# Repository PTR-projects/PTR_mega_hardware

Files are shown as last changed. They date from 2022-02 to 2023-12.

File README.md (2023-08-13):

# KPPTR-hardware

Welcome to the KPPTR-hardware repository! This repository contains the design files for the hardware components used in the KPPTR project. The design files have been created using KiCad 6.0, a powerful open-source electronics design automation suite.

## Project Overview

The design files in this repository correspond to the hardware components that make up the KPPTR project, which enhances the capabilities of DIY amateur rockets and high-altitude balloons. The design files have been crafted using KiCad 6.0, a popular and user-friendly tool for creating electronic schematics and PCB layouts. Both hardware and sofware were developed by PTR member!

## Design Files

The repository includes design files for the various hardware components used in the KPPTR project, including:

- **Schematics**: Detailed electronic schematics that illustrate the connections and components used in the design.
- **PCB Layouts**: PCB layout designs that define the placement and routing of components on the printed circuit board.
- **Libraries**: Custom component libraries and footprints used in the project.

## Getting Started

To access and work with the design files, follow these steps:

1. Clone the repository to your local machine.
2. Install [KiCad 6.0](https://www.kicad.org/download/) if you haven't already.
3. Open the KiCad project files (`.pro` files) in the appropriate subdirectories to access the schematics and PCB layouts.

Feel free to explore the design files and customize them to suit your specific needs. If you make any improvements or modifications to the hardware designs, consider contributing back to the repository to help the community.

## Contributors

- [bartekM](https://gitlab.com/space.tech)
- [https://gitlab.com/andrewziebinski](https://gitlab.com/andrewziebinski)
- [https://gitlab.com/Bdabrowsky](https://gitlab.com/Bdabrowsky)
- [https://gitlab.com/krecik1](https://gitlab.com/krecik1)
- [https://gitlab.com/US_air_force](https://gitlab.com/US_air_force)
- [https://gitlab.com/karmelek96](https://gitlab.com/karmelek96)
- and many others!

## License

This project is licensed under the [MIT License](LICENSE). You can freely use, modify, and distribute the code in accordance with the terms of the license.

Unless required by applicable law or agreed to in writing, this
software is distributed on an "AS IS" BASIS, WITHOUT WARRANTIES OR
CONDITIONS OF ANY KIND, either express or implied.

Thank you for your interest in KPPTR-firmware! If you have any questions or feedback, please don't hesitate to reach out to us. Happy coding and safe flights!

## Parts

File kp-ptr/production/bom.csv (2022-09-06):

Designator | Footprint | Quantity | Value | LCSC Part #
D2 | D_0402_1005Metric | 1 | TBD
R27 | R_0402_1005Metric | 1 | 10k
R34 | R_0402_1005Metric | 1 | 1k
R16 | R_0402_1005Metric | 1 | 10k
R42 | R_0402_1005Metric | 1 | 10k
R59 | R_0402_1005Metric | 1 | 100k
R39 | R_0402_1005Metric | 1 | 1k
R37 | R_0402_1005Metric | 1 | 1k
R15 | R_0402_1005Metric | 1 | 10k
C3 | C_0603_1608Metric | 1 | 10u
R60 | R_0402_1005Metric | 1 | 10k
F1 | Fuse_1210_3225Metric | 1 | 500mA
C24 | C_0603_1608Metric | 1 | 4.7uF
R41 | R_0402_1005Metric | 1 | 1k
R38 | R_0402_1005Metric | 1 | 1k
R8 | R_0402_1005Metric | 1 | 0R
C6 | C_0402_1005Metric | 1 | 100n
C46 | C_0402_1005Metric | 1 | 100nF
U12 | SOT95P275X110-6N | 1 | NL27WZU04DBVT1G
R14 | R_0402_1005Metric | 1 | 4k7
R24 | R_0402_1005Metric | 1 | 10k
C37 | C_0402_1005Metric | 1 | 1uF
R44 | R_0402_1005Metric | 1 | 10k
R36 | R_0402_1005Metric | 1 | 1k
R54 | R_0402_1005Metric | 1 | 10k
Y1 | XTAL_TSX-3225_16.0000MF18X-AC3 | 1 | 7M40000005-40MHz
R25 | R_0402_1005Metric | 1 | 10k
L3 | L_0402_1005Metric | 1 | 10nH
U9 | LDFM33PVR | 1 | LDFM33PVR
C32 | C_0402_1005Metric | 1 | TBD
R50 | R_0402_1005Metric | 1 | 10k
C17 | C_0402_1005Metric | 1 | 1uF
U4 | LIS331 | 1 | H3LIS331
C23 | C_0603_1608Metric | 1 | 4.7uF
C16 | C_0603_1608Metric | 1 | 10uF
R4 | R_0402_1005Metric | 1 | 1k
F3 | Fuse_1210_3225Metric | 1 | 500mA
R55 | R_0402_1005Metric | 1 | 10k
C14 | C_0402_1005Metric | 1 | 12p
C10 | C_0402_1005Metric | 1 | 100n
C49 | C_0402_1005Metric | 1 | 1uF
U6 | SON50P260X260X55-11N | 1 | NJG1156PCD
C42 | C_0402_1005Metric | 1 | 100n
R1 | R_0402_1005Metric | 1 | 1k
C4 | C_0402_1005Metric | 1 | 1u
R52 | R_0402_1005Metric | 1 | 10k
U11 | SON127P500X600X80-9N | 1 | W25Q128JVS
R35 | R_0402_1005Metric | 1 | 1k
L1 | L_0402_1005Metric | 1 | 1.8nH
R58 | R_0402_1005Metric | 1 | 100k
C41 | C_0402_1005Metric | 1 | 100n
F2 | Fuse_1210_3225Metric | 1 | 500mA
AE1 | AMCA31-2R450G-S1F-T3 | 1 | Antenna_Chip
R32 | R_0402_1005Metric | 1 | 10k
D3 | D_SOD-123 | 1 | D_Schottky
C28 | C_0603_1608Metric | 1 | 10uF
C11 | C_0402_1005Metric | 1 | 100n
C12 | C_0402_1005Metric | 1 | 0.1uF
Q4 | DMC2025UFDB | 1 | DMC2025UFDB_v2
R51 | R_0402_1005Metric | 1 | 10k
U1 | ESP32-S3 | 1 | ESP32-S3FN8
R3 | R_0402_1005Metric | 1 | 1k
R30 | R_0402_1005Metric | 1 | DNP
C22 | C_0402_1005Metric | 1 | 100nF
R17 | R_0402_1005Metric | 1 | 100R
FB2 | R_0603_1608Metric | 1 | 1000mA
R21 | R_1206_3216Metric | 1 | DNP
C26 | C_0402_1005Metric | 1 | 1nF
R12 | R_0402_1005Metric | 1 | 1k
F5 | Fuse_1210_3225Metric | 1 | 500mA
C39 | C_0402_1005Metric | 1 | 100nF
U3 | MMC5983MA | 1 | MMC5983MA
R6 | R_0402_1005Metric | 1 | 22R
R47 | R_0402_1005Metric | 1 | 10k
R49 | R_0402_1005Metric | 1 | 100k
R29 | R_0402_1005Metric | 1 | 10k
U2 | MS5607 | 1 | MS560702BA03-50
D4 | D_SOD-123 | 1 | D_Schottky
C9 | C_0402_1005Metric | 1 | 1u
R19 | R_0402_1005Metric | 1 | 100k
C33 | C_0402_1005Metric | 1 | 10n
C50 | C_0402_1005Metric | 1 | 1uF
R13 | R_0402_1005Metric | 1 | 220
R20 | R_0402_1005Metric | 1 | 10k
U5 | XCVR_L76-L | 1 | L76-L
Q5 | DMC2025UFDB | 1 | DMC2025UFDB_v2
R2 | R_0402_1005Metric | 1 | 1k
R11 | R_0402_1005Metric | 1 | 10k
L2 | L_0402_1005Metric | 1 | 2nH
C21 | C_0402_1005Metric | 1 | 100nF
C1 | C_0402_1005Metric | 1 | 4pF
C5 | C_0402_1005Metric | 1 | 1u
R18 | R_0402_1005Metric | 1 | 10k
C20 | C_0603_1608Metric | 1 | 10uF
R23 | R_0402_1005Metric | 1 | 20k
R43 | R_0402_1005Metric | 1 | 10k
R7 | R_0402_1005Metric | 1 | 22R
R9 | R_0402_1005Metric | 1 | 10k
C13 | C_0402_1005Metric | 1 | 1uF
R56 | R_0402_1005Metric | 1 | 10k
C19 | C_0402_1005Metric | 1 | 100nF
C36 | C_0603_1608Metric | 1 | 10u
C44 | C_0402_1005Metric | 1 | 100nF
R45 | R_0402_1005Metric | 1 | 10k
R5 | R_0402_1005Metric | 1 | 10k
R28 | R_0402_1005Metric | 1 | 2k2
FB1 | R_0402_1005Metric | 1 | 200mA
C30 | C_0402_1005Metric | 1 | DNP
F4 | Fuse_1210_3225Metric | 1 | 500mA
C38 | C_0402_1005Metric | 1 | 1uF
D11 | D_SOD-123 | 1 | 1N4148
R48 | R_0402_1005Metric | 1 | 100k
U8 | AZ1117CH-5.0TRG1 | 1 | AZ1117CH-5.0TRG1
R57 | R_0402_1005Metric | 1 | 10k
C31 | C_0402_1005Metric | 1 | 100nF
C40 | C_0402_1005Metric | 1 | 1uF
C43 | C_0603_1608Metric | 1 | 4u7
C7 | C_0402_1005Metric | 1 | 100n
C47 | C_0402_1005Metric | 1 | 1uF
C45 | C_0402_1005Metric | 1 | 100nF
U10 | SOT-23-6 | 1 | USBLC6-2SC6
Q2 | DMC2025UFDB | 1 | DMC2025UFDB_v2
R61 | R_0402_1005Metric | 1 | 10k
Q1 | SOT-23 | 1 | NMOS_SOT23
R62 | R_0402_1005Metric | 1 | 10k
C25 | C_0402_1005Metric | 1 | 56pF
R63 | R_0402_1005Metric | 1 | 10k
C29 | C_0402_1005Metric | 1 | 100nF
Q3 | DMC2025UFDB | 1 | DMC2025UFDB_v2
U7 | LSM6DSO32 | 1 | LSM6DSO32
R31 | R_0402_1005Metric | 1 | 10k
C15 | C_0402_1005Metric | 1 | 12p
C18 | C_0402_1005Metric | 1 | 100nF
R10 | R_0402_1005Metric | 1 | 10k
C2 | C_0402_1005Metric | 1 | 5pF
R40 | R_0402_1005Metric | 1 | 1k
C48 | C_0402_1005Metric | 1 | 1uF
C8 | C_0402_1005Metric | 1 | 10n
R53 | R_0402_1005Metric | 1 | 10k
C35 | C_0603_1608Metric | 1 | 10u
R22 | R_0402_1005Metric | 1 | 100k
R26 | R_0402_1005Metric | 1 | 100k
R46 | R_0402_1005Metric | 1 | 10k
J1 | PinHeader_1x06_P1.27mm_Vertical | 1 | ESP32_PROG_CON
C34 | CP_Elec_10x10 | 1 | TBD
J2 | TerminalBlock_TE_282834-2_1x02_P2.54mm_Horizontal | 1 | Conn_01x02
IC1 | E22-900M22S | 1 | E22-900M22S
J7 | JST_GH_BM10B-GHS-TBT_1x10-1MP_P1.25mm_Vertical | 1 | Conn_01x10_Male
J4 | USB_C_213716 | 1 | USB_C_Receptacle_USB2.0
J10 | TerminalBlock_TE_282834-2_1x02_P2.54mm_Horizontal | 1 | Conn_01x02
D15 | WS2812B-2020 | 1 | WS2812B-2020
J5 | SMA_Amphenol_132289_EdgeMount | 1 | u.fl
ANT2 | APAE1575 13x13x4mm GPS Patch Antenna | 1 | APAE1575R1340ABDD6-T
D12 | LED_0603_1608Metric | 1 | LED
J8 | JST_GH_BM06B-GHS-TBT_1x06-1MP_P1.25mm_Vertical | 1 | Conn_01x06_Male
J12 | TerminalBlock_TE_282834-2_1x02_P2.54mm_Horizontal | 1 | Conn_01x02
D7 | LED_0603_1608Metric | 1 | G
D8 | LED_0603_1608Metric | 1 | LED
D1 | LED_0603_1608Metric | 1 | BLUE
LS1 | Buzzer_12x9.5RM7.6 | 1 | CBT-09427-SMT
J6 | JST_GH_BM06B-GHS-TBT_1x06-1MP_P1.25mm_Vertical | 1 | Conn_01x06_Male
J13 | TerminalBlock_TE_282834-2_1x02_P2.54mm_Horizontal | 1 | Conn_01x02
J3 | TerminalBlock_TE_282834-2_1x02_P2.54mm_Horizontal | 1 | Conn_01x02
D9 | D_0402_1005Metric | 1 | TBD
D13 | WS2812B-2020 | 1 | WS2812B-2020
J11 | TerminalBlock_TE_282834-2_1x02_P2.54mm_Horizontal | 1 | Conn_01x02
J9 | TerminalBlock_TE_282834-2_1x02_P2.54mm_Horizontal | 1 | Conn_01x02_Male
D14 | WS2812B-2020 | 1 | WS2812B-2020
D5 | LED_0603_1608Metric | 1 | G
D10 | LED_0603_1608Metric | 1 | LED
D6 | LED_0603_1608Metric | 1 | G

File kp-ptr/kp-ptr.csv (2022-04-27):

Source: | E:\KPPTRv3\kp-ptr\kp-ptr.kicad_sch
Date: | 26.04.2022 18:11:41
Tool: | Eeschema (6.0.0)
Generator: | C:\Program Files\KiCad\6.0\bin\scripting\plugins/bom_csv_grouped_by_value.py
Component Count: | 149
Individual Components:
Item | Qty | Reference(s) | Value | LibPart | Footprint | Datasheet | AVAILABILITY | Comment | DESCRIPTION | EU_RoHS_Compliance | Field4 | MANUFACTURER | MAXIMUM_PACKAGE_HEIGHT | MF | MP | PACKAGE | PARTREV | PRICE | STANDARD
 |  | ANT1 | TBD | Device:R | Resistor_SMD:R_0402_1005Metric_Pad0.72x0.64mm_HandSolder | ~
 |  | C1 | TBD | Device:C | Capacitor_SMD:C_01005_0402Metric_Pad0.57x0.30mm_HandSolder | ~
 |  | C2 | TBD | Device:C | Capacitor_SMD:C_01005_0402Metric_Pad0.57x0.30mm_HandSolder | ~
 |  | C3 | TBD | Device:C | Capacitor_SMD:C_01005_0402Metric_Pad0.57x0.30mm_HandSolder | ~
 |  | C4 | 10u | Device:C | Capacitor_SMD:C_01005_0402Metric_Pad0.57x0.30mm_HandSolder | ~
 |  | C5 | 1u | Device:C | Capacitor_SMD:C_01005_0402Metric_Pad0.57x0.30mm_HandSolder | ~
 |  | C6 | 1u | Device:C | Capacitor_SMD:C_01005_0402Metric_Pad0.57x0.30mm_HandSolder | ~
 |  | C7 | 100n | Device:C | Capacitor_SMD:C_01005_0402Metric_Pad0.57x0.30mm_HandSolder | ~
 |  | C8 | TBD | Device:C | Capacitor_SMD:C_01005_0402Metric_Pad0.57x0.30mm_HandSolder | ~
 |  | C9 | 10u | Device:C | Capacitor_SMD:C_01005_0402Metric_Pad0.57x0.30mm_HandSolder | ~
 |  | C10 | 1u | Device:C | Capacitor_SMD:C_01005_0402Metric_Pad0.57x0.30mm_HandSolder | ~
 |  | C11 | 100n | Device:C | Capacitor_SMD:C_01005_0402Metric_Pad0.57x0.30mm_HandSolder | ~
 |  | C12 | 100n | Device:C | Capacitor_SMD:C_01005_0402Metric_Pad0.57x0.30mm_HandSolder | ~
 |  | C13 | 0.1uF | Device:C | Capacitor_SMD:C_01005_0402Metric_Pad0.57x0.30mm_HandSolder | ~
 |  | C14 | 1uF | Device:C | Capacitor_SMD:C_01005_0402Metric_Pad0.57x0.30mm_HandSolder | ~
 |  | C15 | 12p | Device:C | Capacitor_SMD:C_01005_0402Metric_Pad0.57x0.30mm_HandSolder | ~
 |  | C16 | 12p | Device:C | Capacitor_SMD:C_01005_0402Metric_Pad0.57x0.30mm_HandSolder | ~
 |  | C17 | 100nF | Device:C | Capacitor_SMD:C_01005_0402Metric_Pad0.57x0.30mm_HandSolder | ~
 |  | C18 | 47p | Device:C | Capacitor_SMD:C_01005_0402Metric_Pad0.57x0.30mm_HandSolder | ~
 |  | C19 | DNP | Device:C | Capacitor_SMD:C_01005_0402Metric_Pad0.57x0.30mm_HandSolder | ~
 |  | C20 | 10uF | Device:C | Capacitor_SMD:C_01005_0402Metric_Pad0.57x0.30mm_HandSolder | ~
 |  | C21 | 1uF | Device:C | Capacitor_SMD:C_01005_0402Metric_Pad0.57x0.30mm_HandSolder | ~
 |  | C22 | 100nF | Device:C | Capacitor_SMD:C_01005_0402Metric_Pad0.57x0.30mm_HandSolder | ~
 |  | C23 | 10uF | Device:C | Capacitor_SMD:C_01005_0402Metric_Pad0.57x0.30mm_HandSolder | ~
 |  | C24 | 100nF | Device:C | Capacitor_SMD:C_01005_0402Metric_Pad0.57x0.30mm_HandSolder | ~
 |  | C25 | 100nF | Device:C | Capacitor_SMD:C_01005_0402Metric_Pad0.57x0.30mm_HandSolder | ~
 |  | C26 | 4.7uF | Device:C | Capacitor_SMD:C_01005_0402Metric_Pad0.57x0.30mm_HandSolder | ~
 |  | C27 | 4.7uF | Device:C | Capacitor_SMD:C_01005_0402Metric_Pad0.57x0.30mm_HandSolder | ~
 |  | C28 | 10uF | Device:C | Capacitor_SMD:C_01005_0402Metric_Pad0.57x0.30mm_HandSolder | ~
 |  | C29 | 100nF | Device:C | Capacitor_SMD:C_01005_0402Metric_Pad0.57x0.30mm_HandSolder | ~
 |  | C30 | 100nF | Device:C | Capacitor_SMD:C_01005_0402Metric_Pad0.57x0.30mm_HandSolder | ~
 |  | C31 | 1uF | Device:C | Capacitor_SMD:C_01005_0402Metric_Pad0.57x0.30mm_HandSolder | ~
 |  | C32 | TBD | Device:C_Polarized | Capacitor_SMD:C_01005_0402Metric_Pad0.57x0.30mm_HandSolder | ~
 |  | C33 | 1uF | Device:C | Capacitor_SMD:C_01005_0402Metric_Pad0.57x0.30mm_HandSolder | ~
 |  | C34 | 100n | Device:C | Capacitor_SMD:C_01005_0402Metric_Pad0.57x0.30mm_HandSolder | ~
 |  | C35 | 10u | Device:C | Capacitor_SMD:C_01005_0402Metric_Pad0.57x0.30mm_HandSolder | ~
 |  | C36 | 100n | Device:C | Capacitor_SMD:C_0402_1005Metric_Pad0.74x0.62mm_HandSolder | ~
 |  | C37 | 100nF | Device:C | Capacitor_SMD:C_01005_0402Metric_Pad0.57x0.30mm_HandSolder | ~
 |  | C38 | 4u7 | Device:C | Capacitor_SMD:C_0805_2012Metric_Pad1.18x1.45mm_HandSolder | ~
 |  | C39 | TBD | Device:C | Capacitor_SMD:C_01005_0402Metric_Pad0.57x0.30mm_HandSolder | ~
 |  | C40 | TBD | Device:C | Capacitor_SMD:C_01005_0402Metric_Pad0.57x0.30mm_HandSolder | ~
 |  | C41 | TBD | Device:C | Capacitor_SMD:C_01005_0402Metric_Pad0.57x0.30mm_HandSolder | ~
 |  | C42 | TBD | Device:C | Capacitor_SMD:C_01005_0402Metric_Pad0.57x0.30mm_HandSolder | ~
 |  | D1 | TBD | Diode:ESD9B3.3ST5G | Diode_SMD:D_SOD-923 | https://www.onsemi.com/pub/Collateral/ESD9B-D.PDF
 |  | D2 | D_Schottky | Device:D_Schottky | Diode_SMD:D_0805_2012Metric_Pad1.15x1.40mm_HandSolder | ~
 |  | D3 | G | Device:LED | LED_SMD:LED_0402_1005Metric_Pad0.77x0.64mm_HandSolder | ~
 |  | D4 | G | Device:LED | LED_SMD:LED_0402_1005Metric_Pad0.77x0.64mm_HandSolder | ~
 |  | D5 | 1N4148 | Diode:1N4148 | Diode_THT:D_DO-35_SOD27_P7.62mm_Horizontal | https://assets.nexperia.com/documents/data-sheet/1N4148_1N4448.pdf
 |  | D6 | LED | Device:LED | LED_SMD:LED_0402_1005Metric_Pad0.77x0.64mm_HandSolder | ~
 |  | D7 | LED | Device:LED | LED_SMD:LED_0402_1005Metric_Pad0.77x0.64mm_HandSolder | ~
 |  | D8 | LED | Device:LED | LED_SMD:LED_0402_1005Metric_Pad0.77x0.64mm_HandSolder | ~
 |  | D9 | LED | Device:LED | LED_SMD:LED_0402_1005Metric_Pad0.77x0.64mm_HandSolder | ~
 |  | D10 | TBD | Diode:ESD9B3.3ST5G | Diode_SMD:D_SOD-923 | https://www.onsemi.com/pub/Collateral/ESD9B-D.PDF
 |  | F1 | 500mA | Device:Polyfuse | Fuse:Fuse_1206_3216Metric_Pad1.42x1.75mm_HandSolder | ~
 |  | F2 | 500mA | Device:Polyfuse | Fuse:Fuse_1206_3216Metric_Pad1.42x1.75mm_HandSolder | ~
 |  | F3 | 500mA | Device:Polyfuse | Fuse:Fuse_1206_3216Metric_Pad1.42x1.75mm_HandSolder | ~
 |  | F4 | 500mA | Device:Polyfuse | Fuse:Fuse_1206_3216Metric_Pad1.42x1.75mm_HandSolder | ~
 |  | FB1 | TBD | Device:R | Resistor_SMD:R_0402_1005Metric_Pad0.72x0.64mm_HandSolder | ~
 |  | IC1 | E22-900M22S | KP-PTR_lib:E22-900M22S | KP-PTR_lib:E22-900M22S
 |  | J1 | ANT1 | Connector_Generic:Conn_01x02 |  | ~
 |  | J2 | Conn_01x02 | Connector_Generic:Conn_01x02 | TerminalBlock_TE-Connectivity:TerminalBlock_TE_282834-2_1x02_P2.54mm_Horizontal | ~
 |  | J3 | Conn_01x02 | Connector_Generic:Conn_01x02 | TerminalBlock_TE-Connectivity:TerminalBlock_TE_282834-2_1x02_P2.54mm_Horizontal | ~
 |  | J4 | USB_C_Receptacle_USB2.0 | Connector:USB_C_Receptacle_USB2.0 | KP-PTR_lib:217B-BC02 | https://www.usb.org/sites/default/files/documents/usb_type-c.zip
 |  | J5 | Micro_SD_Card_Det | Connector:Micro_SD_Card_Det | KP-PTR_lib:GCT_MEM2051-00-195-00-A | https://www.hirose.com/product/en/download_file/key_name/DM3/category/Catalog/doc_file_id/49662/?item_id=195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
 |  | J6 | Conn_01x02 | Connector_Generic:Conn_01x02 | TerminalBlock_TE-Connectivity:TerminalBlock_TE_282834-2_1x02_P2.54mm_Horizontal | ~
 |  | J7 | Conn_01x02 | Connector_Generic:Conn_01x02 | TerminalBlock_TE-Connectivity:TerminalBlock_TE_282834-2_1x02_P2.54mm_Horizontal | ~
 |  | J8 | Conn_01x02 | Connector_Generic:Conn_01x02 | TerminalBlock_TE-Connectivity:TerminalBlock_TE_282834-2_1x02_P2.54mm_Horizontal | ~
 |  | J9 | Conn_01x02 | Connector_Generic:Conn_01x02 | TerminalBlock_TE-Connectivity:TerminalBlock_TE_282834-2_1x02_P2.54mm_Horizontal | ~
 |  | J10 | u.fl | Connector:Conn_Coaxial |  | ~
 |  | J11 | u.fl | Connector:Conn_Coaxial |  | ~
 |  | L1 | L | Device:L |  | ~
 |  | L2 | L | Device:L |  | ~
 |  | L3 | L | Device:L |  | ~
 |  | L4 | 27nH | Device:L |  | ~
 |  | LS1 | CBT-09427-SMT | KP-PTR_lib:CBT-09427-SMT | KP-PTR_lib:BUZZER CBT-09 |  | Unavailable |  | 9 mm, 3.6 V, 87 dB, Surface Mount _SMT_, Magnetic Audio Transducer Buzzer |  |  |  |  | CUI | CBT-09427-SMT | None |  | None
 |  | Q5 | NMOS_SOT23 | Transistor_FET:IRLML2060 | Package_TO_SOT_SMD:SOT-23 | https://www.infineon.com/dgdl/irlml2060pbf.pdf?fileId=5546d462533600a401535664b7fb25ee
 |  | Q6 | NMOS_SOT23 | Transistor_FET:IRLML2060 | Package_TO_SOT_SMD:SOT-23 | https://www.infineon.com/dgdl/irlml2060pbf.pdf?fileId=5546d462533600a401535664b7fb25ee
 |  | Q7 | NMOS_SOT23 | Transistor_FET:IRLML2060 | Package_TO_SOT_SMD:SOT-23 | https://www.infineon.com/dgdl/irlml2060pbf.pdf?fileId=5546d462533600a401535664b7fb25ee
 |  | Q8 | PMOS_SOT23 | Transistor_FET:IRLML6401 | Package_TO_SOT_SMD:SOT-23 | https://www.infineon.com/dgdl/irlml6401pbf.pdf?fileId=5546d462533600a401535668b96d2634
 |  | Q9 | PMOS_SOT23 | Transistor_FET:IRLML6401 | Package_TO_SOT_SMD:SOT-23 | https://www.infineon.com/dgdl/irlml6401pbf.pdf?fileId=5546d462533600a401535668b96d2634
 |  | Q10 | NMOS_SOT23 | Transistor_FET:IRLML2060 | Package_TO_SOT_SMD:SOT-23 | https://www.infineon.com/dgdl/irlml2060pbf.pdf?fileId=5546d462533600a401535664b7fb25ee
 |  | Q11 | NMOS_SOT23 | Transistor_FET:IRLML2060 | Package_TO_SOT_SMD:SOT-23 | https://www.infineon.com/dgdl/irlml2060pbf.pdf?fileId=5546d462533600a401535664b7fb25ee
 |  | Q12 | PMOS_SOT23 | Transistor_FET:IRLML6401 | Package_TO_SOT_SMD:SOT-23 | https://www.infineon.com/dgdl/irlml6401pbf.pdf?fileId=5546d462533600a401535668b96d2634
 |  | Q13 | PMOS_SOT23 | Transistor_FET:IRLML6401 | Package_TO_SOT_SMD:SOT-23 | https://www.infineon.com/dgdl/irlml6401pbf.pdf?fileId=5546d462533600a401535668b96d2634
 |  | R1 | 1k | Device:R | Resistor_SMD:R_0402_1005Metric_Pad0.72x0.64mm_HandSolder | ~
 |  | R2 | 1k | Device:R | Resistor_SMD:R_0402_1005Metric_Pad0.72x0.64mm_HandSolder | ~
 |  | R3 | 22R | Device:R | Resistor_SMD:R_0402_1005Metric_Pad0.72x0.64mm_HandSolder | ~
 |  | R4 | 22R | Device:R | Resistor_SMD:R_0402_1005Metric_Pad0.72x0.64mm_HandSolder | ~
 |  | R5 | 0R | Device:R | Resistor_SMD:R_0402_1005Metric_Pad0.72x0.64mm_HandSolder | ~
 |  | R6 | 10k | Device:R | Resistor_SMD:R_0402_1005Metric_Pad0.72x0.64mm_HandSolder | ~
 |  | R7 | 10k | Device:R | Resistor_SMD:R_0402_1005Metric_Pad0.72x0.64mm_HandSolder | ~
 |  | R8 | 10R | Device:R | Resistor_SMD:R_0402_1005Metric_Pad0.72x0.64mm_HandSolder | ~
 |  | R9 | 10k | Device:R | Resistor_SMD:R_0402_1005Metric_Pad0.72x0.64mm_HandSolder | ~
 |  | R10 | 2k | Device:R | Resistor_SMD:R_0402_1005Metric_Pad0.72x0.64mm_HandSolder | ~
 |  | R11 | 10k | Device:R | Resistor_SMD:R_0402_1005Metric_Pad0.72x0.64mm_HandSolder | ~
 |  | R12 | DNP | Device:R | Resistor_SMD:R_0402_1005Metric_Pad0.72x0.64mm_HandSolder | ~
 |  | R13 | 0R | Device:R | Resistor_SMD:R_0402_1005Metric_Pad0.72x0.64mm_HandSolder | ~
 |  | R17 | 10k | Device:R | Resistor_SMD:R_0402_1005Metric_Pad0.72x0.64mm_HandSolder | ~
 |  | R18 | 10k | Device:R | Resistor_SMD:R_0402_1005Metric_Pad0.72x0.64mm_HandSolder | ~
 |  | R19 | 220 | Device:R | Resistor_SMD:R_0402_1005Metric_Pad0.72x0.64mm_HandSolder | ~
 |  | R20 | 10k | Device:R | Resistor_SMD:R_0402_1005Metric_Pad0.72x0.64mm_HandSolder | ~
 |  | R21 | DNP | Device:R | Resistor_SMD:R_0402_1005Metric_Pad0.72x0.64mm_HandSolder | ~
 |  | R22 | 0R | Device:R | Resistor_SMD:R_0402_1005Metric_Pad0.72x0.64mm_HandSolder | ~
 |  | R23 | DNP | Device:R | Resistor_SMD:R_0402_1005Metric_Pad0.72x0.64mm_HandSolder | ~
 |  | R24 | 100k | Device:R | Resistor_SMD:R_0402_1005Metric_Pad0.72x0.64mm_HandSolder | ~
 |  | R25 | 10k | Device:R | Resistor_SMD:R_0402_1005Metric_Pad0.72x0.64mm_HandSolder | ~
 |  | R26 | DNP | Device:R | Resistor_SMD:R_0402_1005Metric_Pad0.72x0.64mm_HandSolder | ~
 |  | R27 | 100k | Device:R | Resistor_SMD:R_0402_1005Metric_Pad0.72x0.64mm_HandSolder | ~
 |  | R29 | 20k | Device:R | Resistor_SMD:R_0402_1005Metric_Pad0.72x0.64mm_HandSolder | ~
 |  | R30 | 10k | Device:R | Resistor_SMD:R_0402_1005Metric_Pad0.72x0.64mm_HandSolder | ~
 |  | R32 | 100k | Device:R | Resistor_SMD:R_0402_1005Metric_Pad0.72x0.64mm_HandSolder | ~
 |  | R33 | 100k | Device:R | Resistor_SMD:R_0402_1005Metric_Pad0.72x0.64mm_HandSolder | ~
 |  | R34 | 100k | Device:R | Resistor_SMD:R_0402_1005Metric_Pad0.72x0.64mm_HandSolder | ~
 |  | R35 | 100k | Device:R | Resistor_SMD:R_0402_1005Metric_Pad0.72x0.64mm_HandSolder | ~
 |  | R36 | 100k | Device:R | Resistor_SMD:R_0402_1005Metric_Pad0.72x0.64mm_HandSolder | ~
 |  | R37 | 10k | Device:R | Resistor_SMD:R_0402_1005Metric_Pad0.72x0.64mm_HandSolder | ~
 |  | R38 | 1k | Device:R | Resistor_SMD:R_0402_1005Metric_Pad0.72x0.64mm_HandSolder | ~
 |  | R39 | 1k | Device:R | Resistor_SMD:R_0402_1005Metric_Pad0.72x0.64mm_HandSolder | ~
 |  | R40 | 1k | Device:R | Resistor_SMD:R_01005_0402Metric_Pad0.57x0.30mm_HandSolder | ~
 |  | R41 | 10k | Device:R | Resistor_SMD:R_01005_0402Metric_Pad0.57x0.30mm_HandSolder | ~
 |  | R42 | 10k | Device:R | Resistor_SMD:R_01005_0402Metric_Pad0.57x0.30mm_HandSolder | ~
 |  | R43 | 10k | Device:R | Resistor_SMD:R_01005_0402Metric_Pad0.57x0.30mm_HandSolder | ~
 |  | R44 | 10k | Device:R | Resistor_SMD:R_01005_0402Metric_Pad0.57x0.30mm_HandSolder | ~
 |  | R45 | 100k | Device:R | Resistor_SMD:R_01005_0402Metric_Pad0.57x0.30mm_HandSolder | ~
 |  | R46 | 100k | Device:R | Resistor_SMD:R_01005_0402Metric_Pad0.57x0.30mm_HandSolder | ~
 |  | R47 | 10k | Device:R | Resistor_SMD:R_01005_0402Metric_Pad0.57x0.30mm_HandSolder | ~
 |  | R48 | 10k | Device:R | Resistor_SMD:R_01005_0402Metric_Pad0.57x0.30mm_HandSolder | ~
 |  | R49 | 10k | Device:R | Resistor_SMD:R_01005_0402Metric_Pad0.57x0.30mm_HandSolder | ~
 |  | R50 | 10k | Device:R | Resistor_SMD:R_01005_0402Metric_Pad0.57x0.30mm_HandSolder | ~
 |  | R51 | 10k | Device:R | Resistor_SMD:R_01005_0402Metric_Pad0.57x0.30mm_HandSolder | ~
 |  | R52 | 10k | Device:R | Resistor_SMD:R_01005_0402Metric_Pad0.57x0.30mm_HandSolder | ~
 |  | R53 | 10k | Device:R | Resistor_SMD:R_01005_0402Metric_Pad0.57x0.30mm_HandSolder | ~
 |  | R54 | 10k | Device:R | Resistor_SMD:R_01005_0402Metric_Pad0.57x0.30mm_HandSolder | ~
 |  | R55 | 100k | Device:R | Resistor_SMD:R_01005_0402Metric_Pad0.57x0.30mm_HandSolder | ~
 |  | R56 | 100k | Device:R | Resistor_SMD:R_01005_0402Metric_Pad0.57x0.30mm_HandSolder | ~
 |  | R57 | 10k | Device:R | Resistor_SMD:R_01005_0402Metric_Pad0.57x0.30mm_HandSolder | ~
 |  | R58 | 10k | Device:R | Resistor_SMD:R_01005_0402Metric_Pad0.57x0.30mm_HandSolder | ~
 |  | R59 | 10k | Device:R | Resistor_SMD:R_01005_0402Metric_Pad0.57x0.30mm_HandSolder | ~
 |  | R60 | 10k | Device:R | Resistor_SMD:R_01005_0402Metric_Pad0.57x0.30mm_HandSolder | ~
 |  | U1 | ESP32-S3FN8 | KP-PTR_lib:ESP32-S3 | KP-PTR_lib:ESP32-S3
 |  | U2 | NC7WV04P6X | KP-PTR_lib:NC7WV04P6X
 |  | U3 | MS560702BA03-50 | KP-PTR_lib:MS560702BA03-50 | KP-PTR_lib:MS5607 |  |  | MS560702BA03-50 |  | Compliant
 |  | U4 | MMC5983MA | KP-PTR_lib:MMC5983MA | KP-PTR_lib:MMC5983MA |  |  |  |  |  |  | Memsic Inc. | 1.00 mm |  |  |  | A |  | IPC 7351B
 |  | U5 | H3LIS331 | KP-PTR_lib:LIS331 | KP-PTR_lib:LIS331 |  |  |  |  |  | IC-12675
 |  | U6 | L96-M33 | KP-PTR_lib:L96-M33 | KP-PTR_lib:XCVR_L96-M33 |  | Unavailable |  | L96 is a concurrent multi-GNSS receiver module with embedded chip antenna. With 33 tracking channels, 99 acquisition channels and 210 PRN channels, L96 supports concurrent reception of up to three GNSS systems _GPS+GLONASS+Galileo_ |  |  |  |  | Quectel Wireless Solutions Co., Ltd | L96 | SOIC-8 Quectel Wireless Solutions Co., Ltd |  | None
 |  | U7 | LSM6DSO32 | KP-PTR_lib:LSM6DSO32 | KP-PTR_lib:LSM6DSO32
 |  | U8 | SPX3819M5-L-3-3 | Regulator_Linear:SPX3819M5-L-3-3 | Package_TO_SOT_SMD:SOT-23-5 | https://www.exar.com/content/document.ashx?id=22106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
 |  | U10 | USBLC6-2SC6 | Power_Protection:USBLC6-2SC6 | Package_TO_SOT_SMD:SOT-23-6 | https://www.st.com/resource/en/datasheet/usblc6-2.pdf
 |  | Y1 | 7M40000005-40MHz | KP-PTR_lib:7M40000005-40MHz | KP-PTR_lib:XTAL_TSX-3225_16.0000MF18X-AC3 |  |  |  |  |  |  | SEIKO EPSON CORPORATION |  |  |  |  |  |  | Manufacturer Recommendations
Collated Components:
Item | Qty | Reference(s) | Value | LibPart | Footprint | Datasheet | AVAILABILITY | Comment | DESCRIPTION | EU_RoHS_Compliance | Field4 | MANUFACTURER | MAXIMUM_PACKAGE_HEIGHT | MF | MP | PACKAGE | PARTREV | PRICE | STANDARD
1 | 2 | ANT1, FB1 | TBD | Device:R | Resistor_SMD:R_0402_1005Metric_Pad0.72x0.64mm_HandSolder | ~
2 | 8 | C1, C2, C3, C8, C39, C40, C41, C42 | TBD | Device:C | Capacitor_SMD:C_01005_0402Metric_Pad0.57x0.30mm_HandSolder | ~
3 | 3 | C4, C9, C35 | 10u | Device:C | Capacitor_SMD:C_01005_0402Metric_Pad0.57x0.30mm_HandSolder | ~
4 | 3 | C5, C6, C10 | 1u | Device:C | Capacitor_SMD:C_01005_0402Metric_Pad0.57x0.30mm_HandSolder | ~
5 | 4 | C7, C11, C12, C34 | 100n | Device:C | Capacitor_SMD:C_01005_0402Metric_Pad0.57x0.30mm_HandSolder | ~
6 | 1 | C13 | 0.1uF | Device:C | Capacitor_SMD:C_01005_0402Metric_Pad0.57x0.30mm_HandSolder | ~
7 | 4 | C14, C21, C31, C33 | 1uF | Device:C | Capacitor_SMD:C_01005_0402Metric_Pad0.57x0.30mm_HandSolder | ~
8 | 2 | C15, C16 | 12p | Device:C | Capacitor_SMD:C_01005_0402Metric_Pad0.57x0.30mm_HandSolder | ~
9 | 7 | C17, C22, C24, C25, C29, C30, C37 | 100nF | Device:C | Capacitor_SMD:C_01005_0402Metric_Pad0.57x0.30mm_HandSolder | ~
10 | 1 | C18 | 47p | Device:C | Capacitor_SMD:C_01005_0402Metric_Pad0.57x0.30mm_HandSolder | ~
11 | 1 | C19 | DNP | Device:C | Capacitor_SMD:C_01005_0402Metric_Pad0.57x0.30mm_HandSolder | ~
12 | 3 | C20, C23, C28 | 10uF | Device:C | Capacitor_SMD:C_01005_0402Metric_Pad0.57x0.30mm_HandSolder | ~
13 | 2 | C26, C27 | 4.7uF | Device:C | Capacitor_SMD:C_01005_0402Metric_Pad0.57x0.30mm_HandSolder | ~
14 | 1 | C32 | TBD | Device:C_Polarized | Capacitor_SMD:C_01005_0402Metric_Pad0.57x0.30mm_HandSolder | ~
15 | 1 | C36 | 100n | Device:C | Capacitor_SMD:C_0402_1005Metric_Pad0.74x0.62mm_HandSolder | ~
16 | 1 | C38 | 4u7 | Device:C | Capacitor_SMD:C_0805_2012Metric_Pad1.18x1.45mm_HandSolder | ~
17 | 2 | D1, D10 | TBD | Diode:ESD9B3.3ST5G | Diode_SMD:D_SOD-923 | https://www.onsemi.com/pub/Collateral/ESD9B-D.PDF
18 | 1 | D2 | D_Schottky | Device:D_Schottky | Diode_SMD:D_0805_2012Metric_Pad1.15x1.40mm_HandSolder | ~
19 | 2 | D3, D4 | G | Device:LED | LED_SMD:LED_0402_1005Metric_Pad0.77x0.64mm_HandSolder | ~
20 | 1 | D5 | 1N4148 | Diode:1N4148 | Diode_THT:D_DO-35_SOD27_P7.62mm_Horizontal | https://assets.nexperia.com/documents/data-sheet/1N4148_1N4448.pdf
21 | 4 | D6, D7, D8, D9 | LED | Device:LED | LED_SMD:LED_0402_1005Metric_Pad0.77x0.64mm_HandSolder | ~
22 | 4 | F1, F2, F3, F4 | 500mA | Device:Polyfuse | Fuse:Fuse_1206_3216Metric_Pad1.42x1.75mm_HandSolder | ~
23 | 1 | IC1 | E22-900M22S | KP-PTR_lib:E22-900M22S | KP-PTR_lib:E22-900M22S
24 | 1 | J1 | ANT1 | Connector_Generic:Conn_01x02 |  | ~
25 | 6 | J2, J3, J6, J7, J8, J9 | Conn_01x02 | Connector_Generic:Conn_01x02 | TerminalBlock_TE-Connectivity:TerminalBlock_TE_282834-2_1x02_P2.54mm_Horizontal | ~
26 | 1 | J4 | USB_C_Receptacle_USB2.0 | Connector:USB_C_Receptacle_USB2.0 | KP-PTR_lib:217B-BC02 | https://www.usb.org/sites/default/files/documents/usb_type-c.zip
27 | 1 | J5 | Micro_SD_Card_Det | Connector:Micro_SD_Card_Det | KP-PTR_lib:GCT_MEM2051-00-195-00-A | https://www.hirose.com/product/en/download_file/key_name/DM3/category/Catalog/doc_file_id/49662/?item_id=195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
28 | 2 | J10, J11 | u.fl | Connector:Conn_Coaxial |  | ~
29 | 3 | L1, L2, L3 | L | Device:L |  | ~
30 | 1 | L4 | 27nH | Device:L |  | ~
31 | 1 | LS1 | CBT-09427-SMT | KP-PTR_lib:CBT-09427-SMT | KP-PTR_lib:BUZZER CBT-09 |  | Unavailable |  | 9 mm, 3.6 V, 87 dB, Surface Mount _SMT_, Magnetic Audio Transducer Buzzer |  |  |  |  | CUI | CBT-09427-SMT | None |  | None
32 | 5 | Q5, Q6, Q7, Q10, Q11 | NMOS_SOT23 | Transistor_FET:IRLML2060 | Package_TO_SOT_SMD:SOT-23 | https://www.infineon.com/dgdl/irlml2060pbf.pdf?fileId=5546d462533600a401535664b7fb25ee
33 | 4 | Q8, Q9, Q12, Q13 | PMOS_SOT23 | Transistor_FET:IRLML6401 | Package_TO_SOT_SMD:SOT-23 | https://www.infineon.com/dgdl/irlml6401pbf.pdf?fileId=5546d462533600a401535668b96d2634
34 | 4 | R1, R2, R38, R39 | 1k | Device:R | Resistor_SMD:R_0402_1005Metric_Pad0.72x0.64mm_HandSolder | ~
35 | 2 | R3, R4 | 22R | Device:R | Resistor_SMD:R_0402_1005Metric_Pad0.72x0.64mm_HandSolder | ~
36 | 3 | R5, R13, R22 | 0R | Device:R | Resistor_SMD:R_0402_1005Metric_Pad0.72x0.64mm_HandSolder | ~
37 | 10 | R6, R7, R9, R11, R17, R18, R20, R25, R30, R37 | 10k | Device:R | Resistor_SMD:R_0402_1005Metric_Pad0.72x0.64mm_HandSolder | ~
38 | 1 | R8 | 10R | Device:R | Resistor_SMD:R_0402_1005Metric_Pad0.72x0.64mm_HandSolder | ~
39 | 1 | R10 | 2k | Device:R | Resistor_SMD:R_0402_1005Metric_Pad0.72x0.64mm_HandSolder | ~
40 | 4 | R12, R21, R23, R26 | DNP | Device:R | Resistor_SMD:R_0402_1005Metric_Pad0.72x0.64mm_HandSolder | ~
41 | 1 | R19 | 220 | Device:R | Resistor_SMD:R_0402_1005Metric_Pad0.72x0.64mm_HandSolder | ~
42 | 7 | R24, R27, R32, R33, R34, R35, R36 | 100k | Device:R | Resistor_SMD:R_0402_1005Metric_Pad0.72x0.64mm_HandSolder | ~
43 | 1 | R29 | 20k | Device:R | Resistor_SMD:R_0402_1005Metric_Pad0.72x0.64mm_HandSolder | ~
44 | 1 | R40 | 1k | Device:R | Resistor_SMD:R_01005_0402Metric_Pad0.57x0.30mm_HandSolder | ~
45 | 16 | R41, R42, R43, R44, R47, R48, R49, R50, R51, R52, R53, R54, R57, R58, R59, R60 | 10k | Device:R | Resistor_SMD:R_01005_0402Metric_Pad0.57x0.30mm_HandSolder | ~
46 | 4 | R45, R46, R55, R56 | 100k | Device:R | Resistor_SMD:R_01005_0402Metric_Pad0.57x0.30mm_HandSolder | ~
47 | 1 | U1 | ESP32-S3FN8 | KP-PTR_lib:ESP32-S3 | KP-PTR_lib:ESP32-S3
48 | 1 | U2 | NC7WV04P6X | KP-PTR_lib:NC7WV04P6X
49 | 1 | U3 | MS560702BA03-50 | KP-PTR_lib:MS560702BA03-50 | KP-PTR_lib:MS5607 |  |  | MS560702BA03-50 |  | Compliant
50 | 1 | U4 | MMC5983MA | KP-PTR_lib:MMC5983MA | KP-PTR_lib:MMC5983MA |  |  |  |  |  |  | Memsic Inc. | 1.00 mm |  |  |  | A |  | IPC 7351B
51 | 1 | U5 | H3LIS331 | KP-PTR_lib:LIS331 | KP-PTR_lib:LIS331 |  |  |  |  |  | IC-12675
52 | 1 | U6 | L96-M33 | KP-PTR_lib:L96-M33 | KP-PTR_lib:XCVR_L96-M33 |  | Unavailable |  | L96 is a concurrent multi-GNSS receiver module with embedded chip antenna. With 33 tracking channels, 99 acquisition channels and 210 PRN channels, L96 supports concurrent reception of up to three GNSS systems _GPS+GLONASS+Galileo_ |  |  |  |  | Quectel Wireless Solutions Co., Ltd | L96 | SOIC-8 Quectel Wireless Solutions Co., Ltd |  | None
53 | 1 | U7 | LSM6DSO32 | KP-PTR_lib:LSM6DSO32 | KP-PTR_lib:LSM6DSO32
54 | 1 | U8 | SPX3819M5-L-3-3 | Regulator_Linear:SPX3819M5-L-3-3 | Package_TO_SOT_SMD:SOT-23-5 | https://www.exar.com/content/document.ashx?id=22106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
55 | 1 | U10 | USBLC6-2SC6 | Power_Protection:USBLC6-2SC6 | Package_TO_SOT_SMD:SOT-23-6 | https://www.st.com/resource/en/datasheet/usblc6-2.pdf
56 | 1 | Y1 | 7M40000005-40MHz | KP-PTR_lib:7M40000005-40MHz | KP-PTR_lib:XTAL_TSX-3225_16.0000MF18X-AC3 |  |  |  |  |  |  | SEIKO EPSON CORPORATION |  |  |  |  |  |  | Manufacturer Recommendations

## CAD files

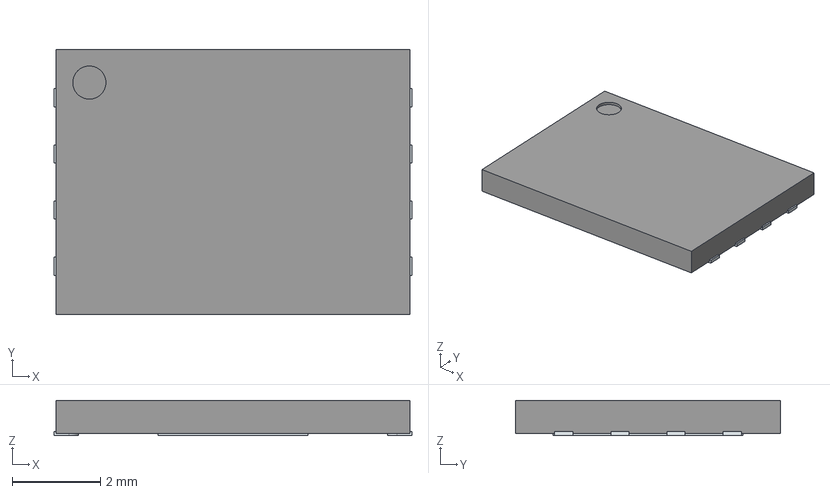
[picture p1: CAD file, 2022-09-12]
kp-ptr/3D models/W25Q256JVEIQ.stp
8.10 x 6.00 x 0.8 mm
ThermalPin
PinsArrayLR

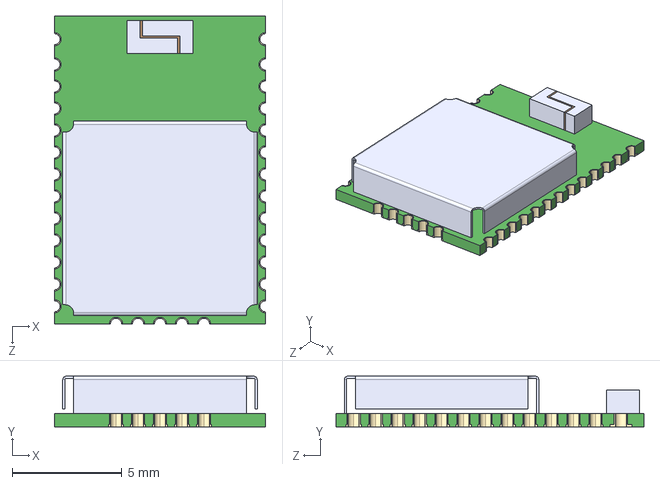
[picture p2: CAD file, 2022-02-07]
kp-ptr/ublox 3D models/CAM-M8Q-0.step
9.60 x 2.30 x 14.0 mm

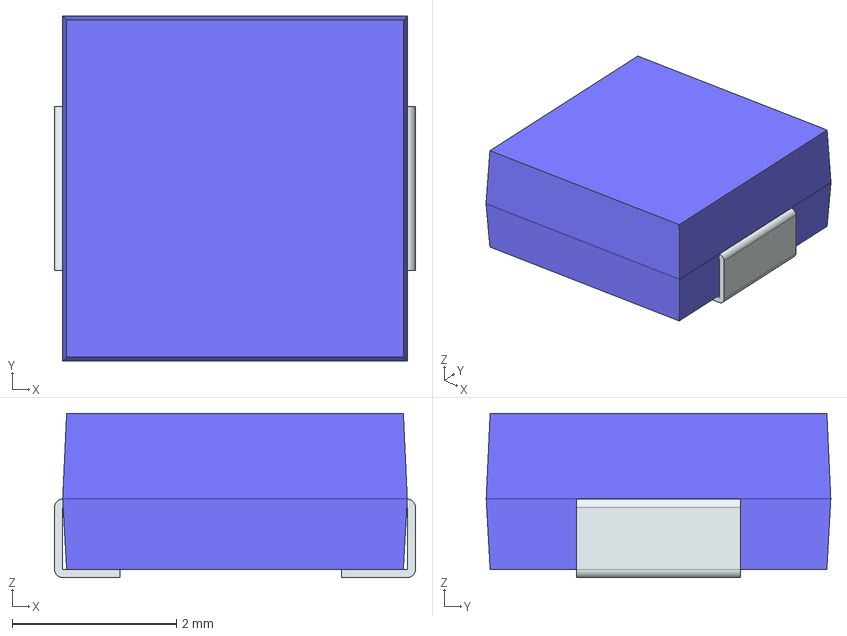
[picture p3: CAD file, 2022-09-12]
kp-ptr/3D models/MWSA0402S-2R2MT.stp
4.40 x 4.20 x 2.00 mm
FilletPin1
FilletPin2

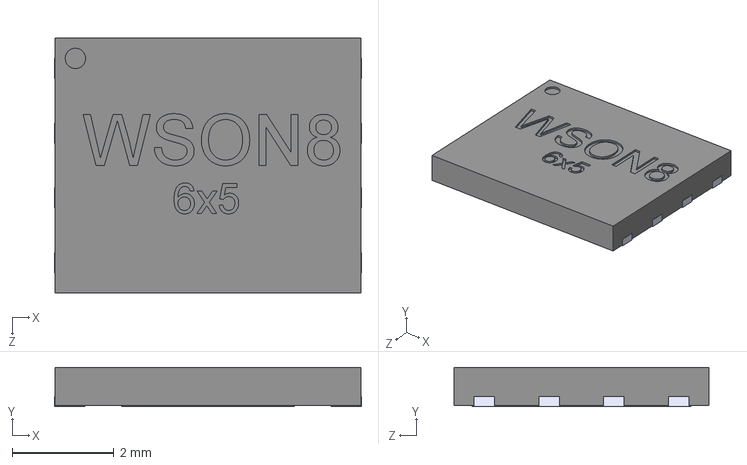
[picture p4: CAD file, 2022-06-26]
kp-ptr/3D models/WSON8-6x5.STEP
6.02 x 0.77 x 5.00 mm

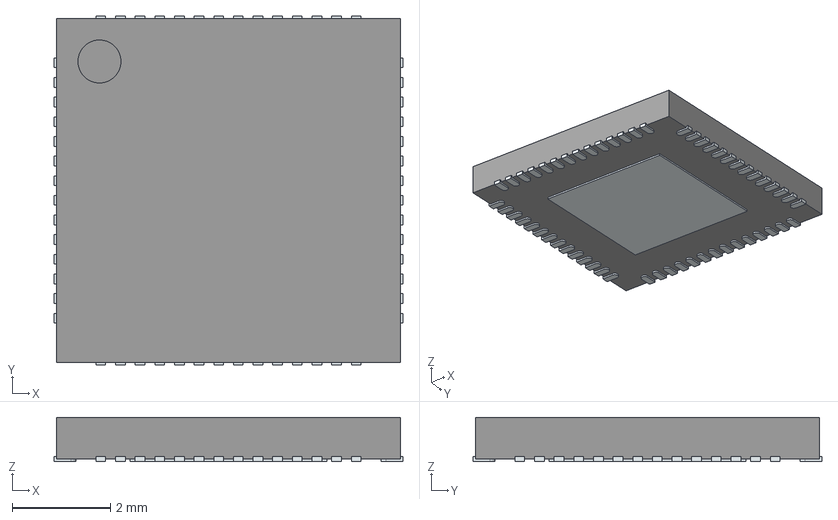
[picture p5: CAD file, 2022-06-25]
kp-ptr/3D models/ESP32-S3FN8.stp
7.10 x 7.10 x 0.9 mm
ThermalPin
PinsArrayLR
PinsArrayTB

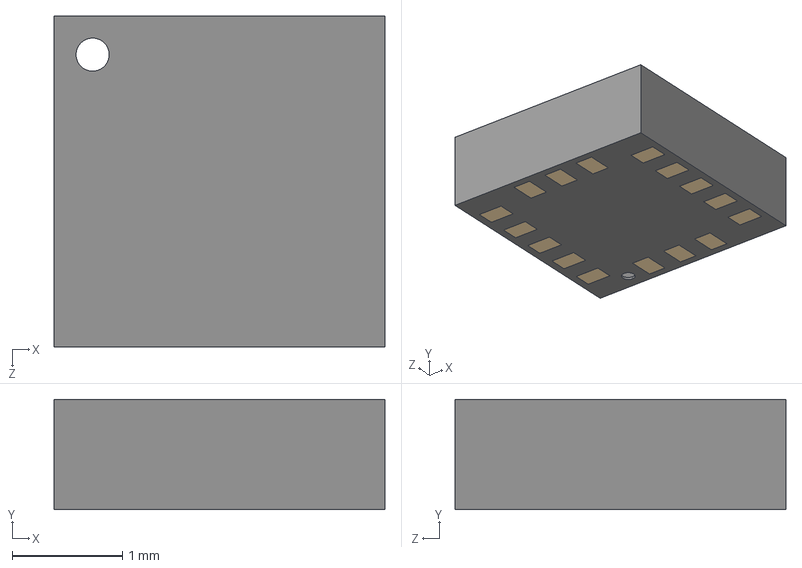
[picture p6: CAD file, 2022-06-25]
kp-ptr/3D models/LSM6DS0.STEP
3.00 x 1.00 x 3.00 mm

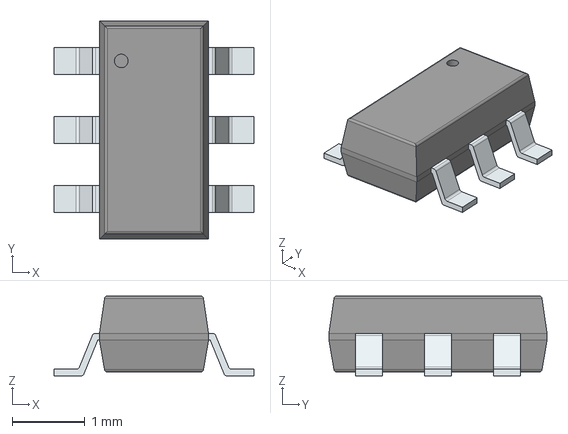
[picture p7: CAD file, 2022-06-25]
kp-ptr/3D models/NL27WZU04DBVT1G.stp
2.75 x 3.00 x 1.10 mm
PinsArrayLR

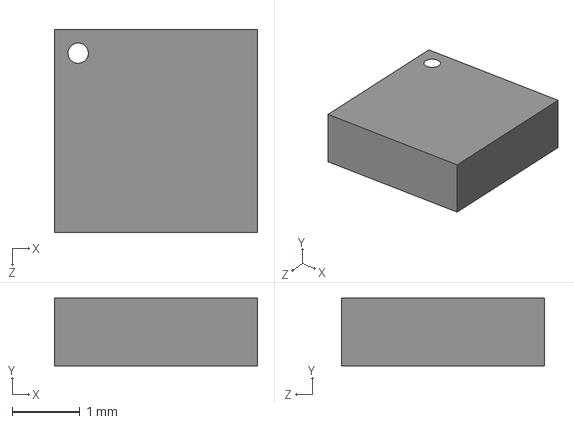
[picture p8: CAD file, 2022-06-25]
kp-ptr/3D models/MMC5983MA--3DModel-STEP-269445.STEP
3.00 x 1.00 x 3.00 mm

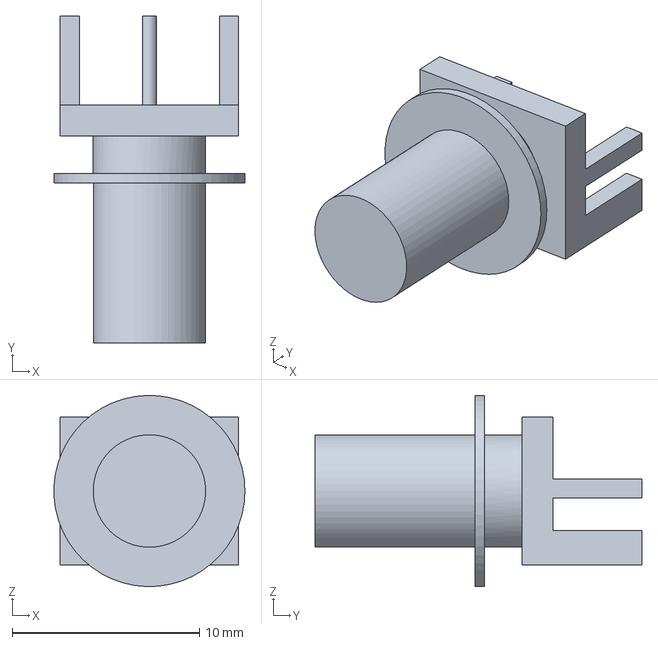
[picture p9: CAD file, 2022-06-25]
kp-ptr/3D models/Amphenol_-_132289.step
10.2 x 17.5 x 10.2 mm

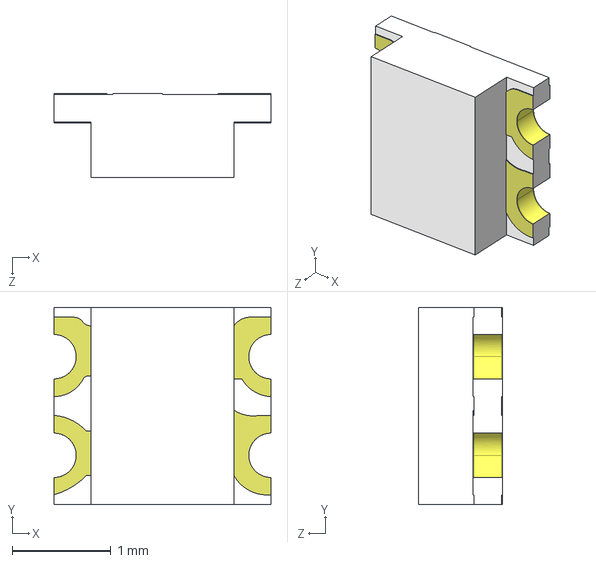
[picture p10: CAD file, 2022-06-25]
kp-ptr/3D models/WS2812B-2020.stp
2.20 x 2.00 x 0.85 mm

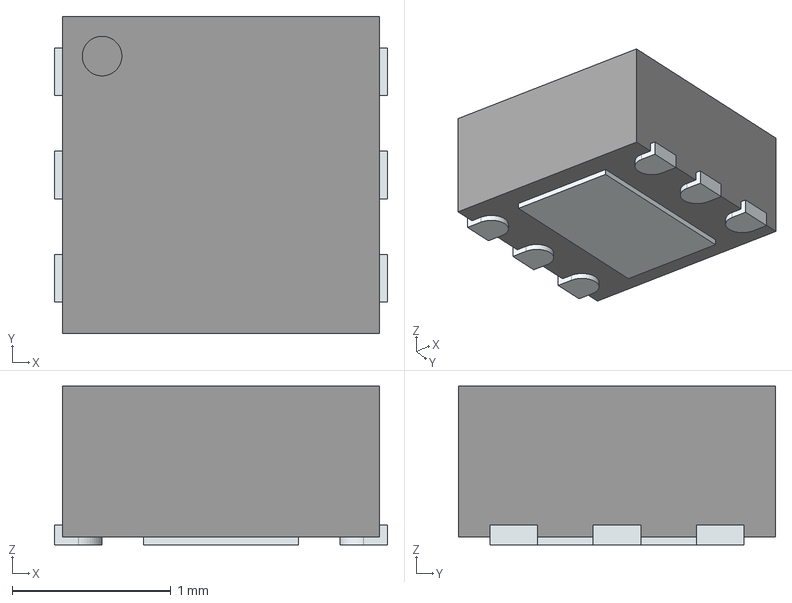
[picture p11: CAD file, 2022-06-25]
kp-ptr/3D models/LDFM33PVR.stp
2.10 x 2.00 x 1.00 mm
ThermalPin
PinsArrayLR

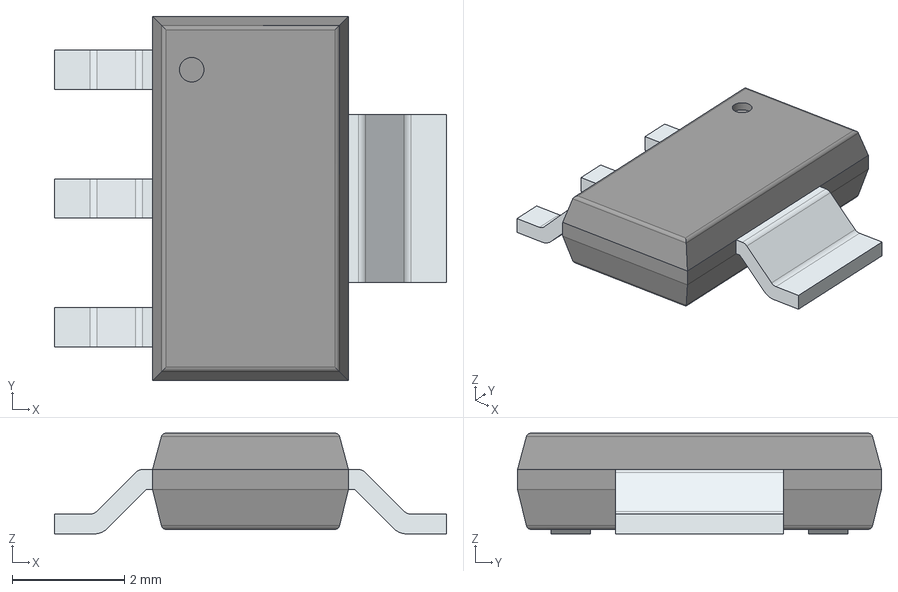
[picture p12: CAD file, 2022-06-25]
kp-ptr/3D models/AZ1117CH-5.0TRG1.stp
7.00 x 6.50 x 1.80 mm
PinsArrayL
FilletPinR

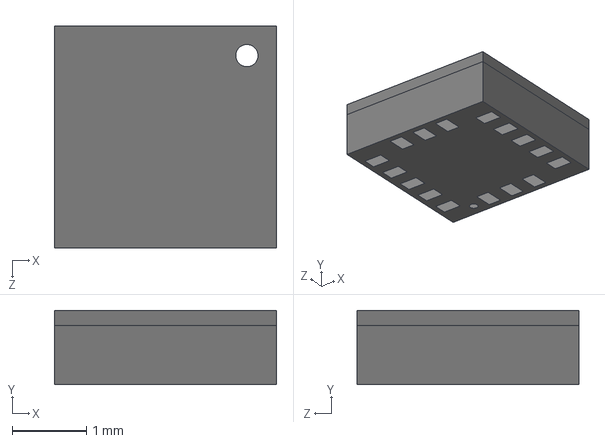
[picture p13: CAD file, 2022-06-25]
kp-ptr/3D models/H3LIS100DLTR.stp
3.00 x 1.00 x 3.00 mm

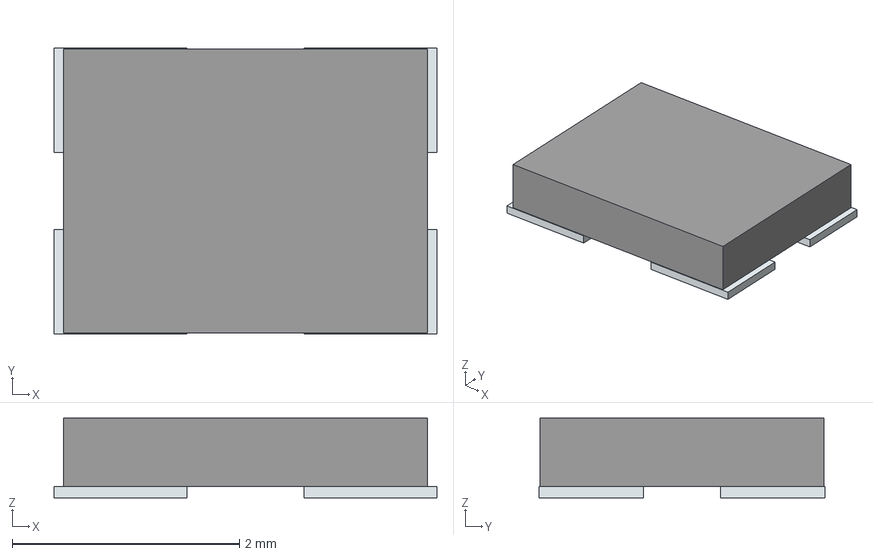
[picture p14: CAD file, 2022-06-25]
kp-ptr/3D models/TSX-3225_16.0000MF18X-AC3.stp
3.37 x 2.52 x 0.7 mm
Pins

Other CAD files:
kp-ptr/3D models/W25Q128JVSIM.stp
kp-ptr/3D models/AMCA31-2R450G-S1F-T3--3DModel-STEP-400430.STEP
kp-ptr/3D models/SOT-223_DIO.step
kp-ptr/3D models/150040GS73240.stp
kp-ptr/3D models/2137160001.stp
kp-ptr/3D models/282834-2--3DModel-STEP-1.STEP
kp-ptr/3D models/APAE1575.STEP
kp-ptr/3D models/DFN_M33PVR_STM.step
kp-ptr/3D models/E22-900M22S v2.step
kp-ptr/3D models/MS560702BA03-50.step
kp-ptr/3D models/SOT95P275X110-6N.step
kp-ptr/3D models/TPS62140ARGTR.stp
kp-ptr/3D models/ublox_max_m8.step

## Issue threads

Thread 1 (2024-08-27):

USB CC lines not used

bartekM-pl, 2024-08-27:
All current HW revisions (v0.1, v1, v1.1) have a bug - USB CC lines are not connected to GND with 5.1k resistors. This result in inability to connect to board using USB C - USB C cable. USB A - USB C cables still works ok.

Closed 2025-06-22.

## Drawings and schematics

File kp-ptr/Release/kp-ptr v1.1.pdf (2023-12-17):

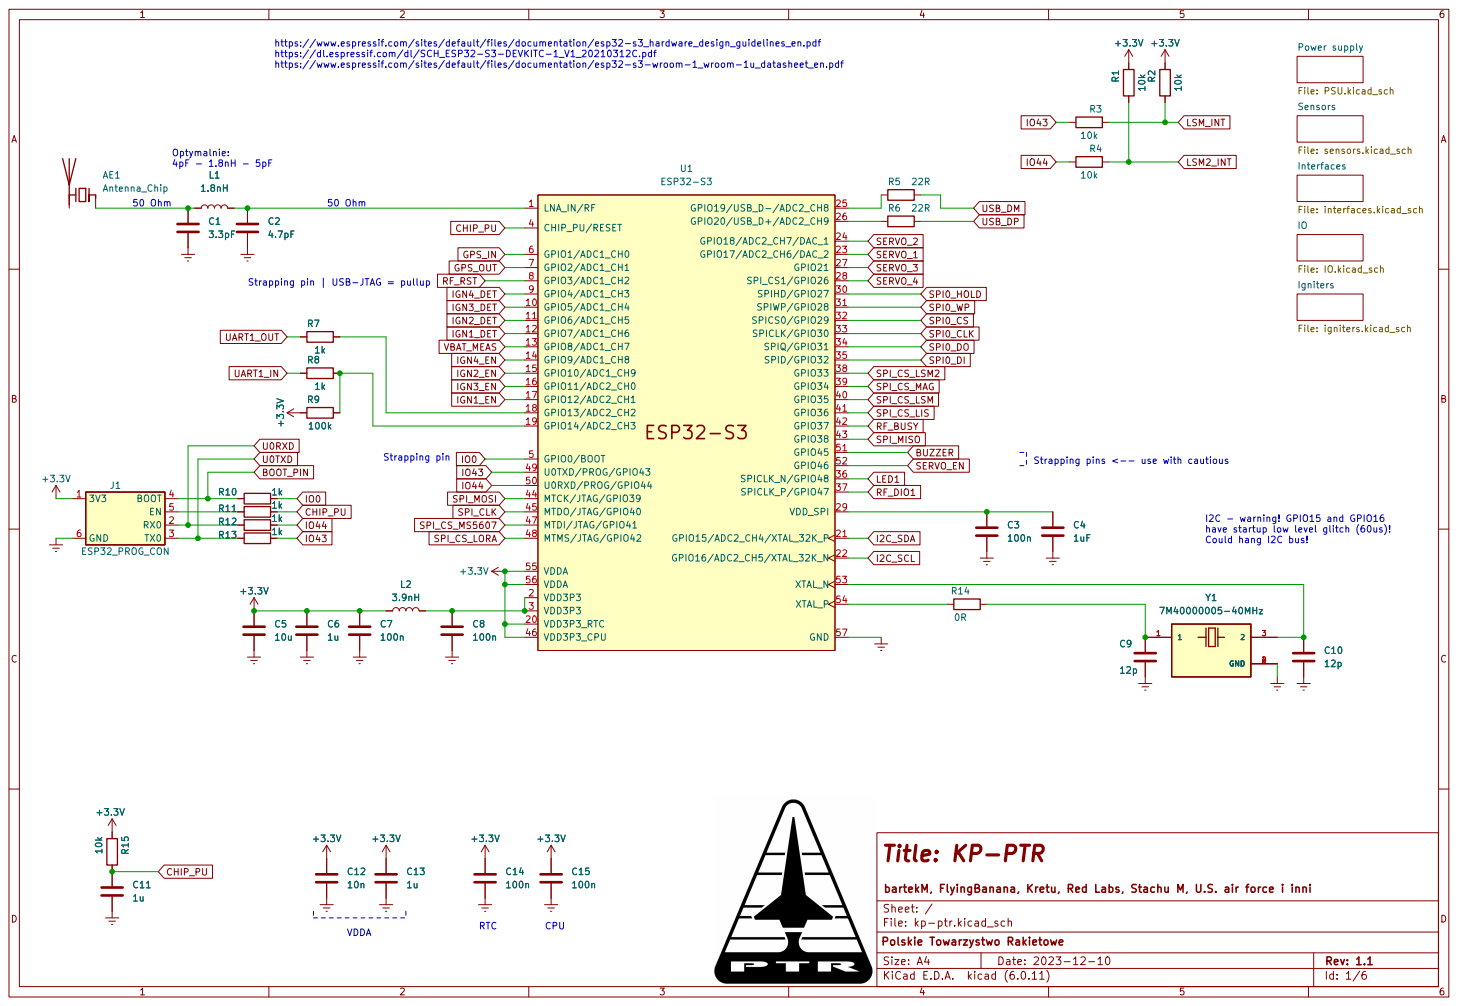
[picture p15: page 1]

https://www.espressif.com/sites/default/files/documentation/esp32-s3_hardware_design_guidelines_en.pdf
https://dl.espressif.com/dl/SCH_ESP32-S3-DEVKITC-1_V1_20210312C.pdf
https://www.espressif.com/sites/default/files/documentation/esp32-s3-wroom-1_wroom-1u_datasheet_en.pdf

Interfaces File: interfaces.kicad_sch Power supply File: PSU.kicad_sch

Id: 1/6 Title: KP-PTR

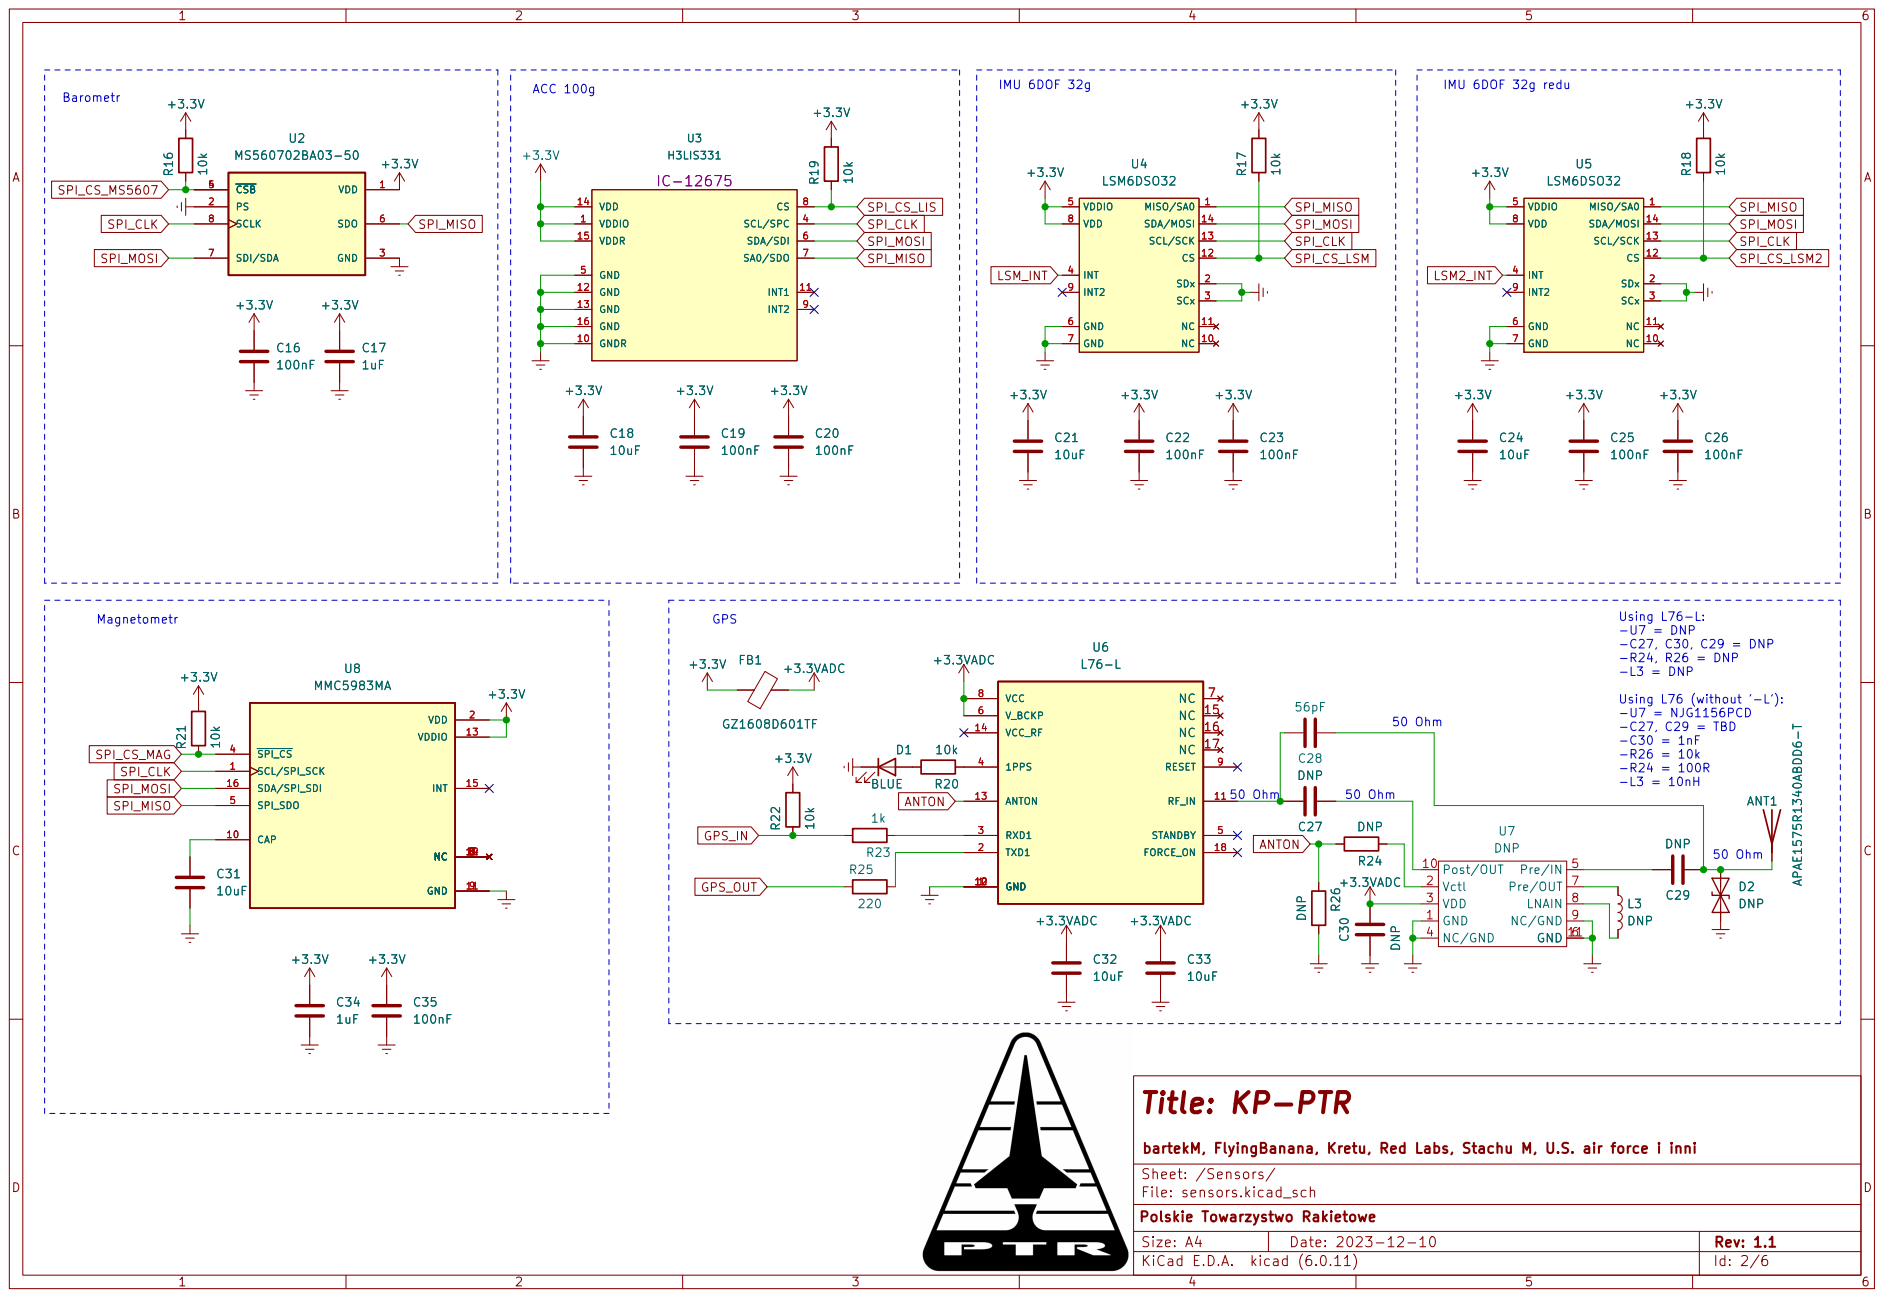
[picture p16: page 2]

Id: 2/6 Title: KP-PTR

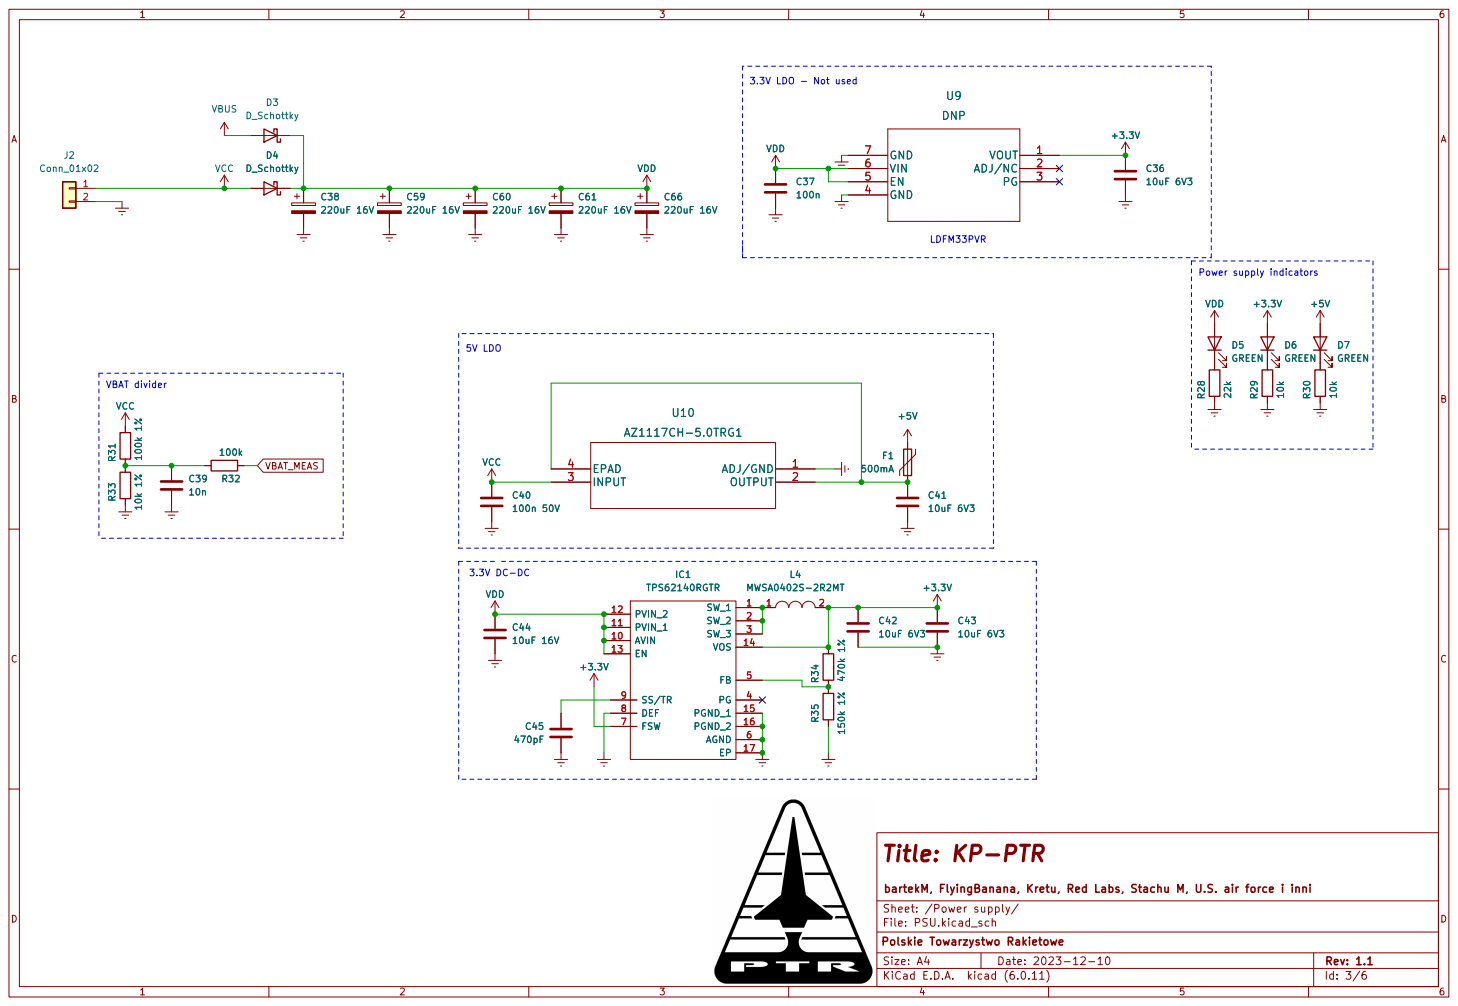
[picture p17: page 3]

Id: 3/6 Title: KP-PTR

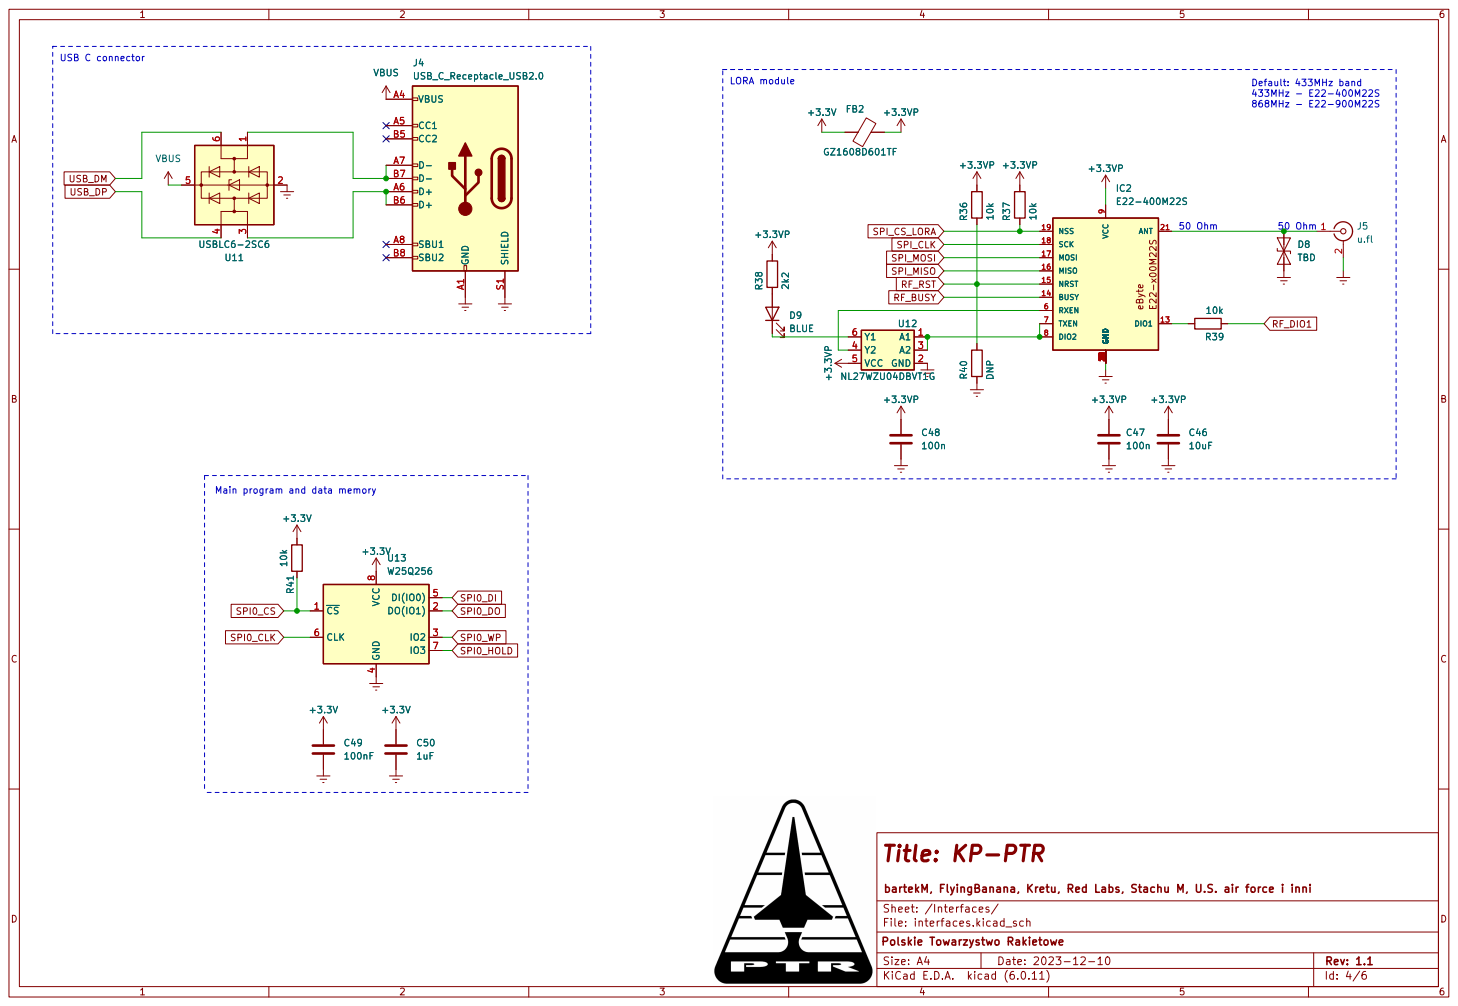
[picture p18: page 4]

Id: 4/6 Title: KP-PTR

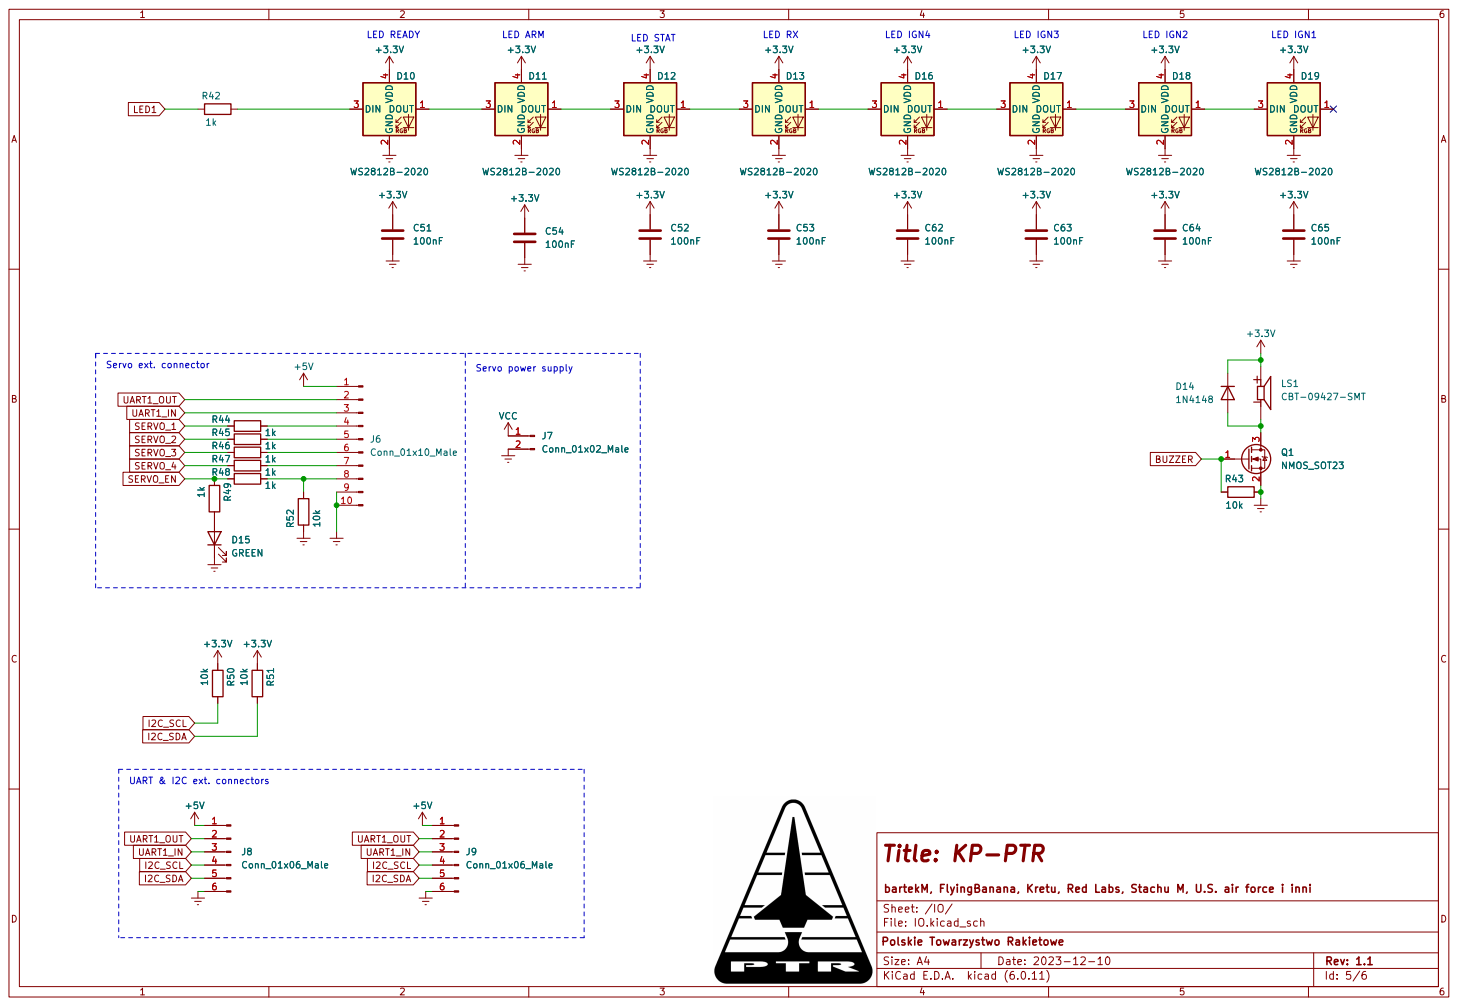
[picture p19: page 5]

Id: 5/6 Title: KP-PTR

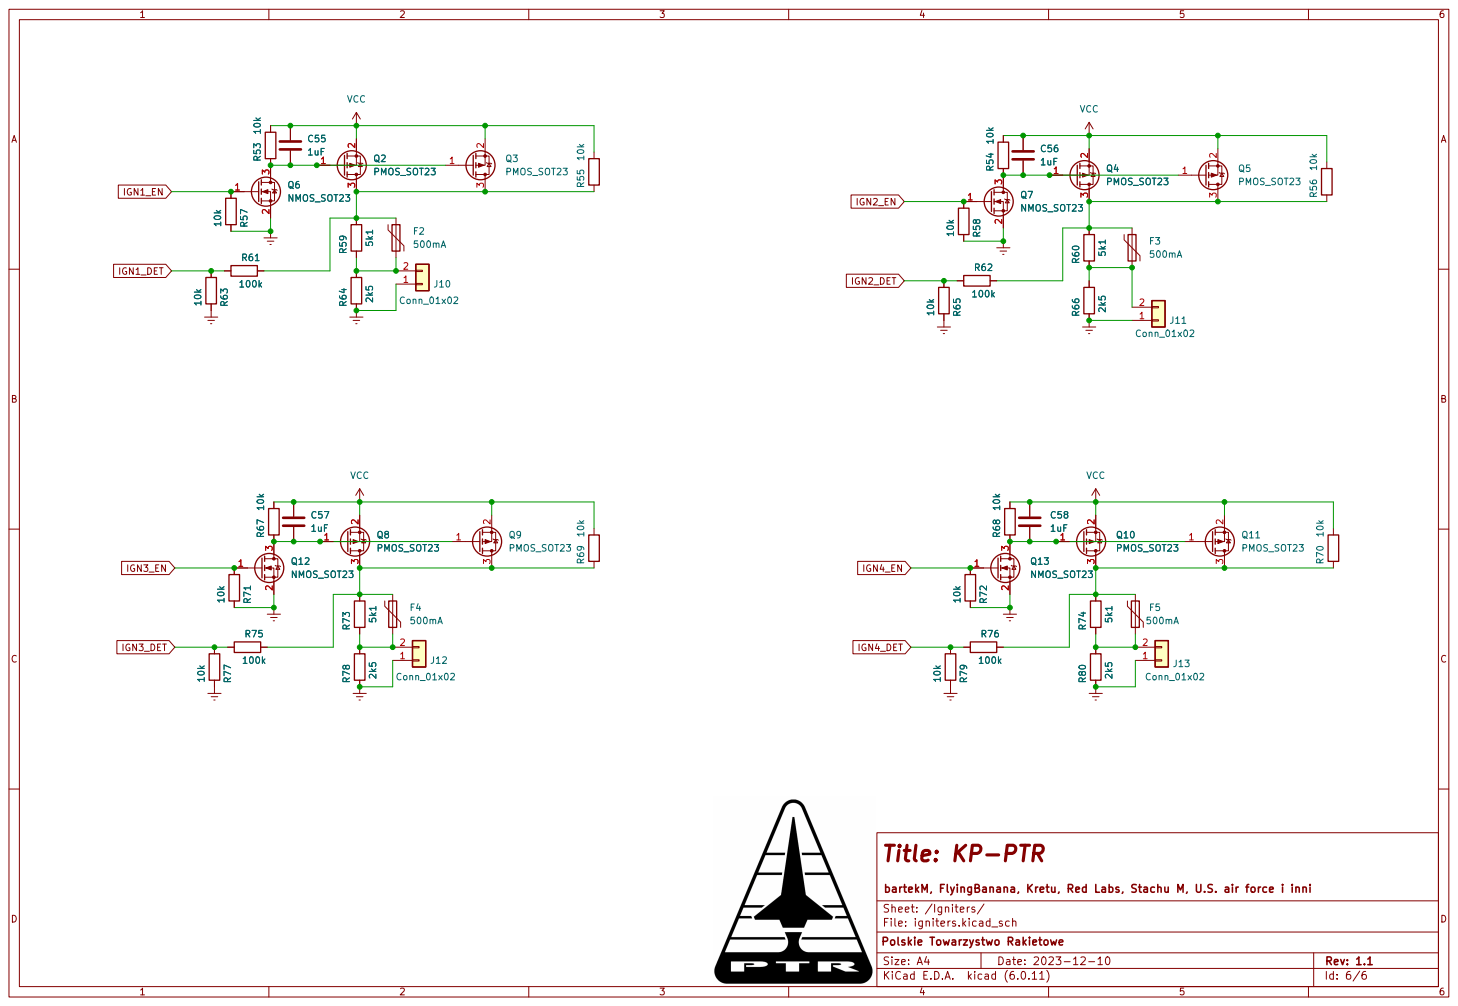
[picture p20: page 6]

Id: 6/6 Title: KP-PTR

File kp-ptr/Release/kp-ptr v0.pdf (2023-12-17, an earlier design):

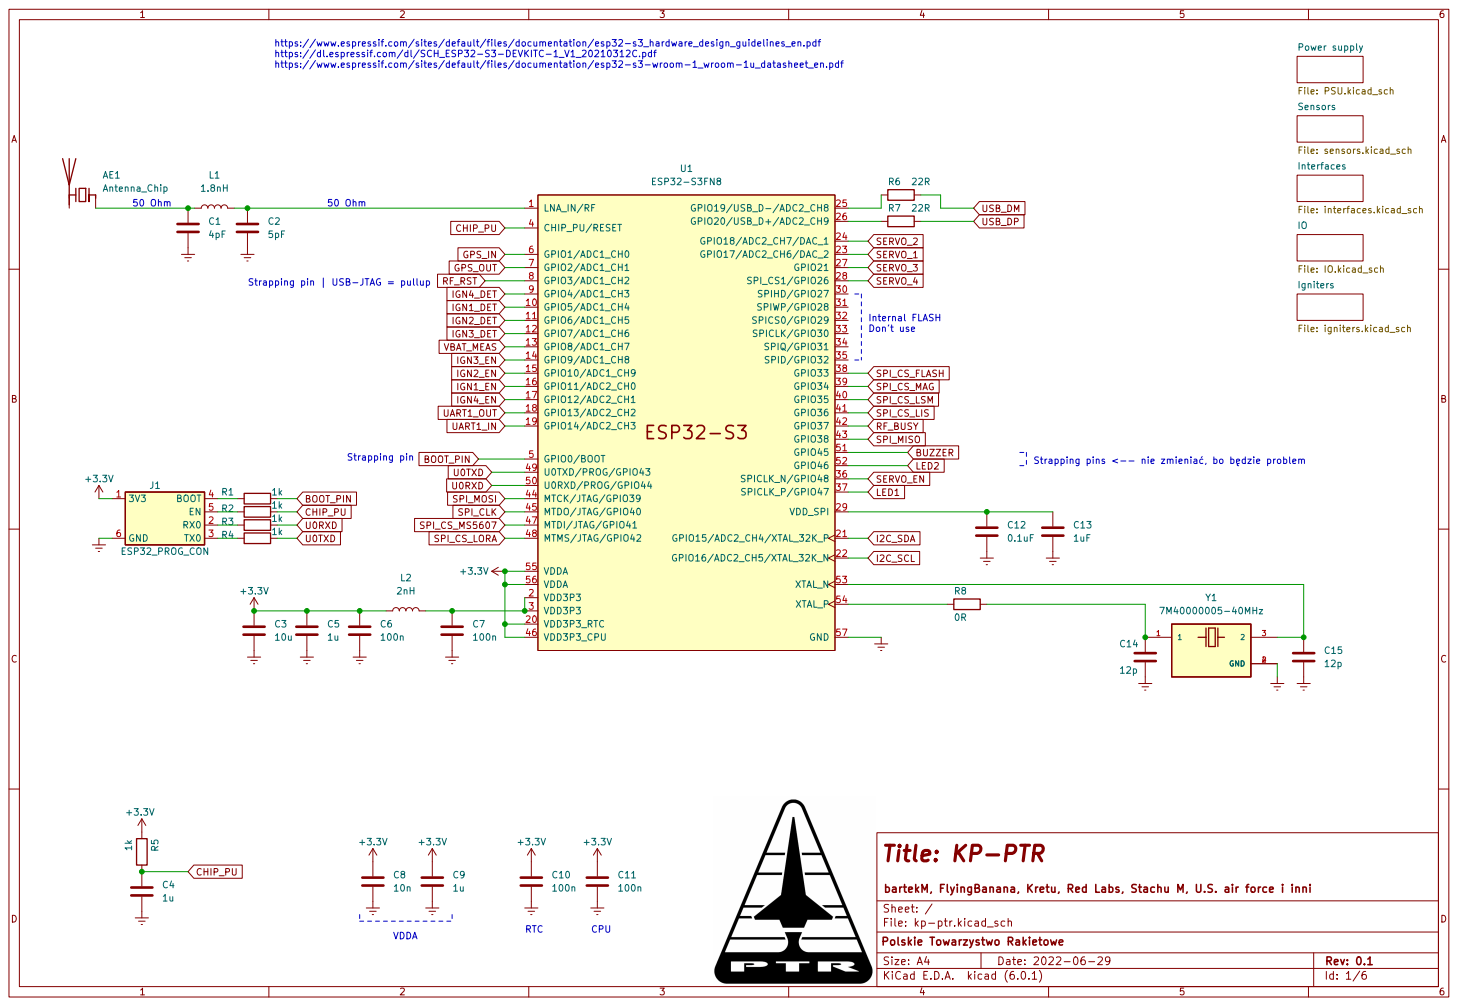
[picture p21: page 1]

https://www.espressif.com/sites/default/files/documentation/esp32-s3_hardware_design_guidelines_en.pdf
https://dl.espressif.com/dl/SCH_ESP32-S3-DEVKITC-1_V1_20210312C.pdf
https://www.espressif.com/sites/default/files/documentation/esp32-s3-wroom-1_wroom-1u_datasheet_en.pdf 50 Ohm

Interfaces File: interfaces.kicad_sch Sensors File: sensors.kicad_sch Power supply File: PSU.kicad_sch

IGN1_DET Strapping pin | USB-JTAG = pullup

Id: 1/6 Title: KP-PTR

bartekM, FlyingBanana, Kretu, Red Labs, Stachu M, U.S. air force i inni
File: kp-ptr.kicad_sch Sheet: / Polskie Towarzystwo Rakietowe

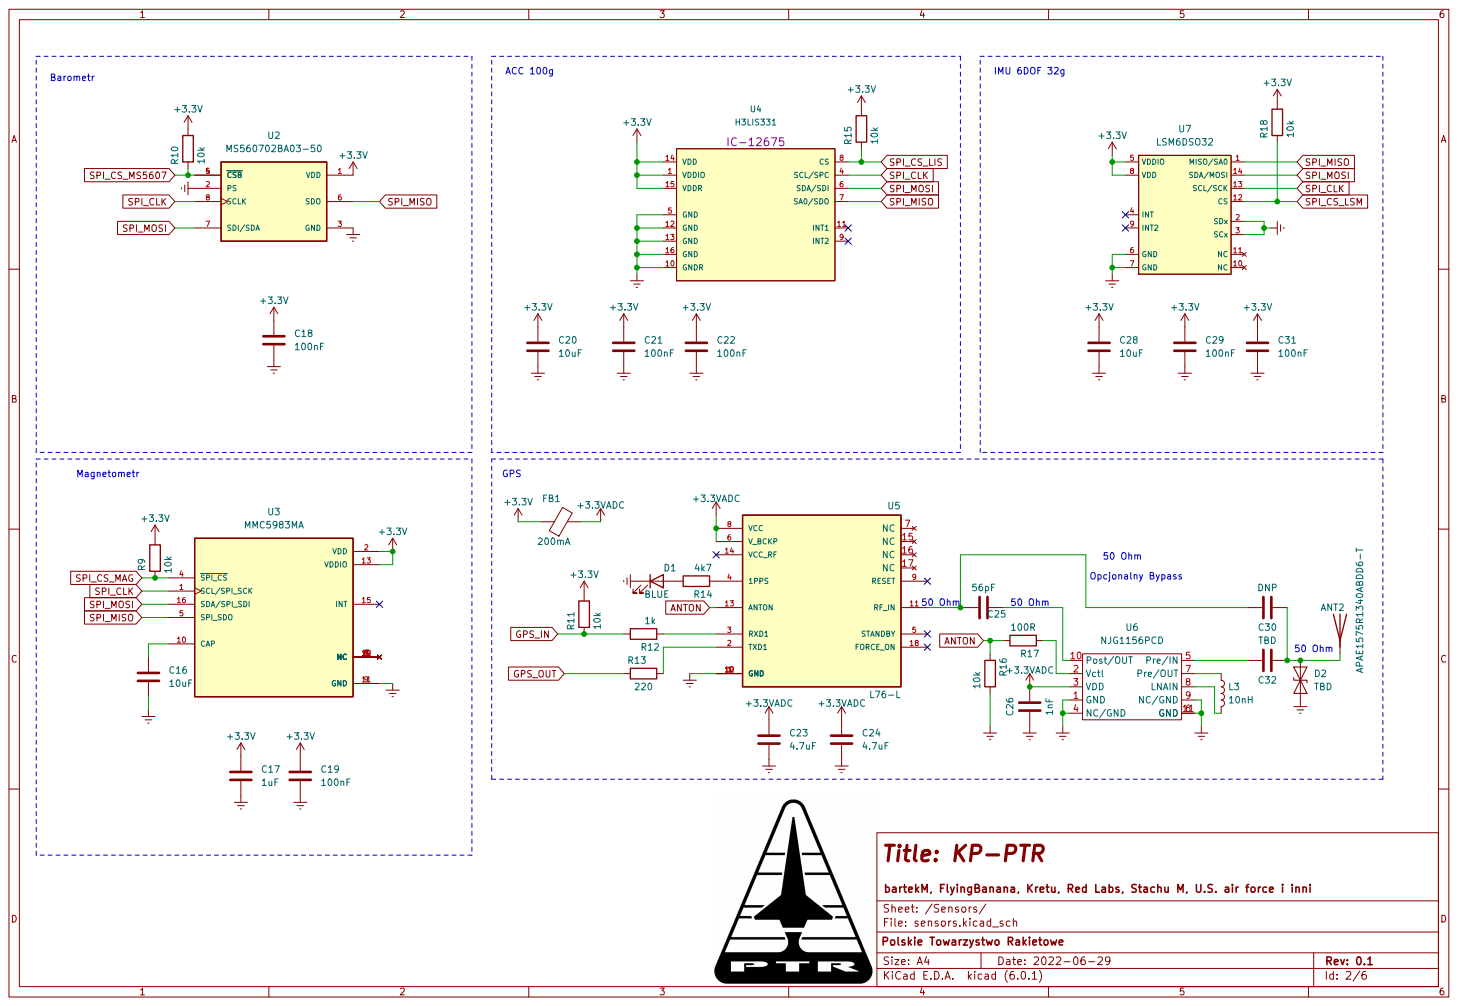
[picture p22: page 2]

Id: 2/6 Title: KP-PTR

bartekM, FlyingBanana, Kretu, Red Labs, Stachu M, U.S. air force i inni
File: sensors.kicad_sch Sheet: /Sensors/ Polskie Towarzystwo Rakietowe

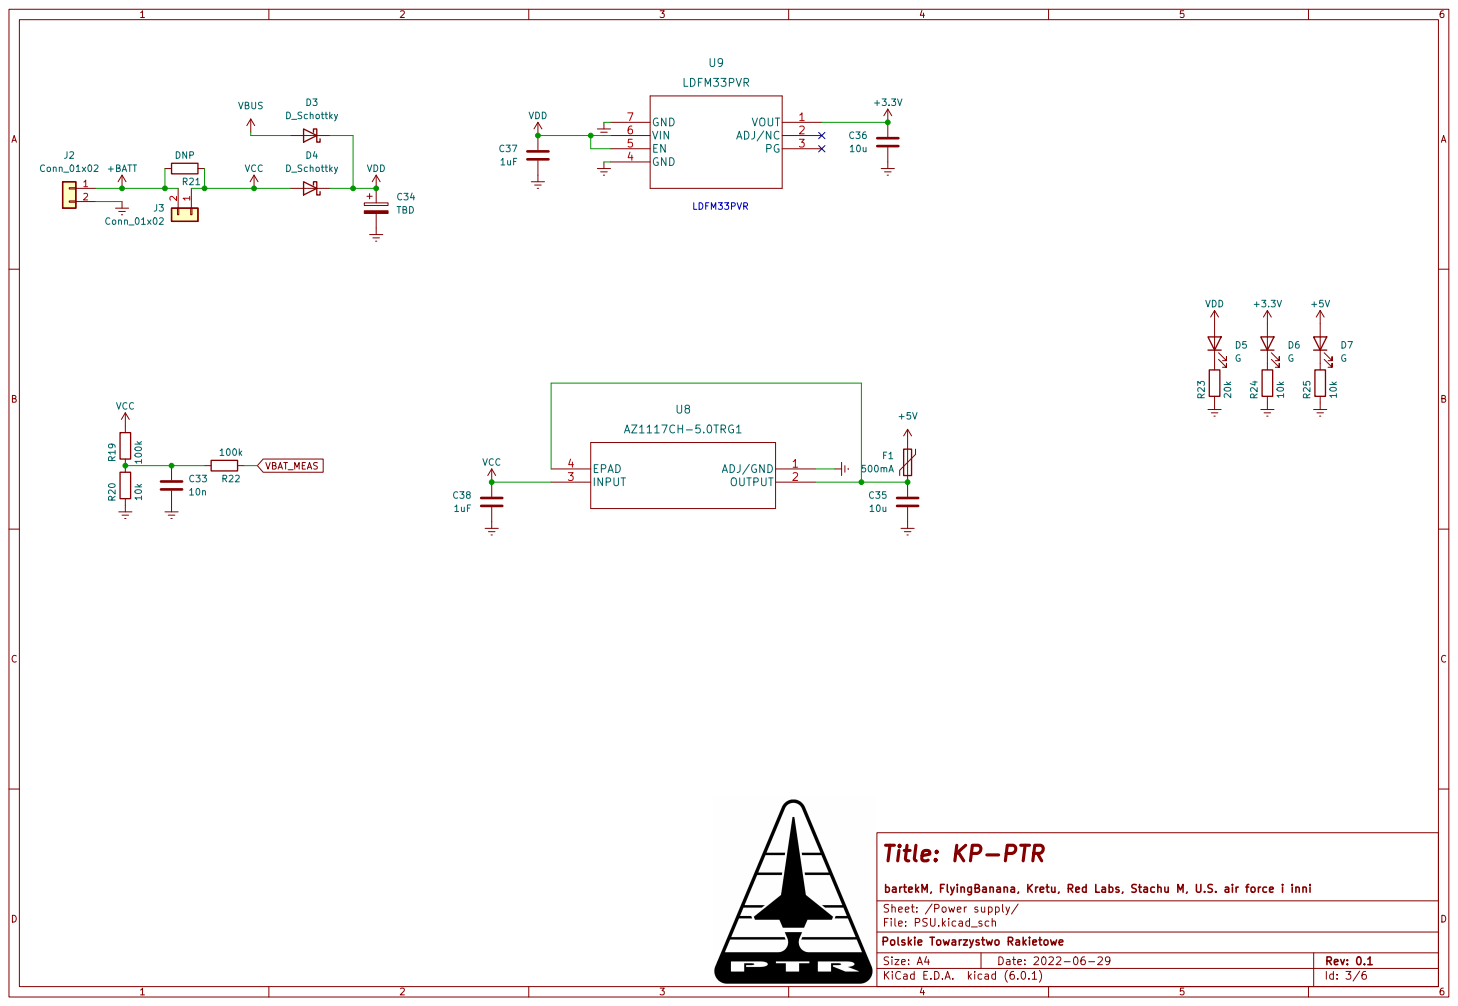
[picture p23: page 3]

Id: 3/6 Title: KP-PTR

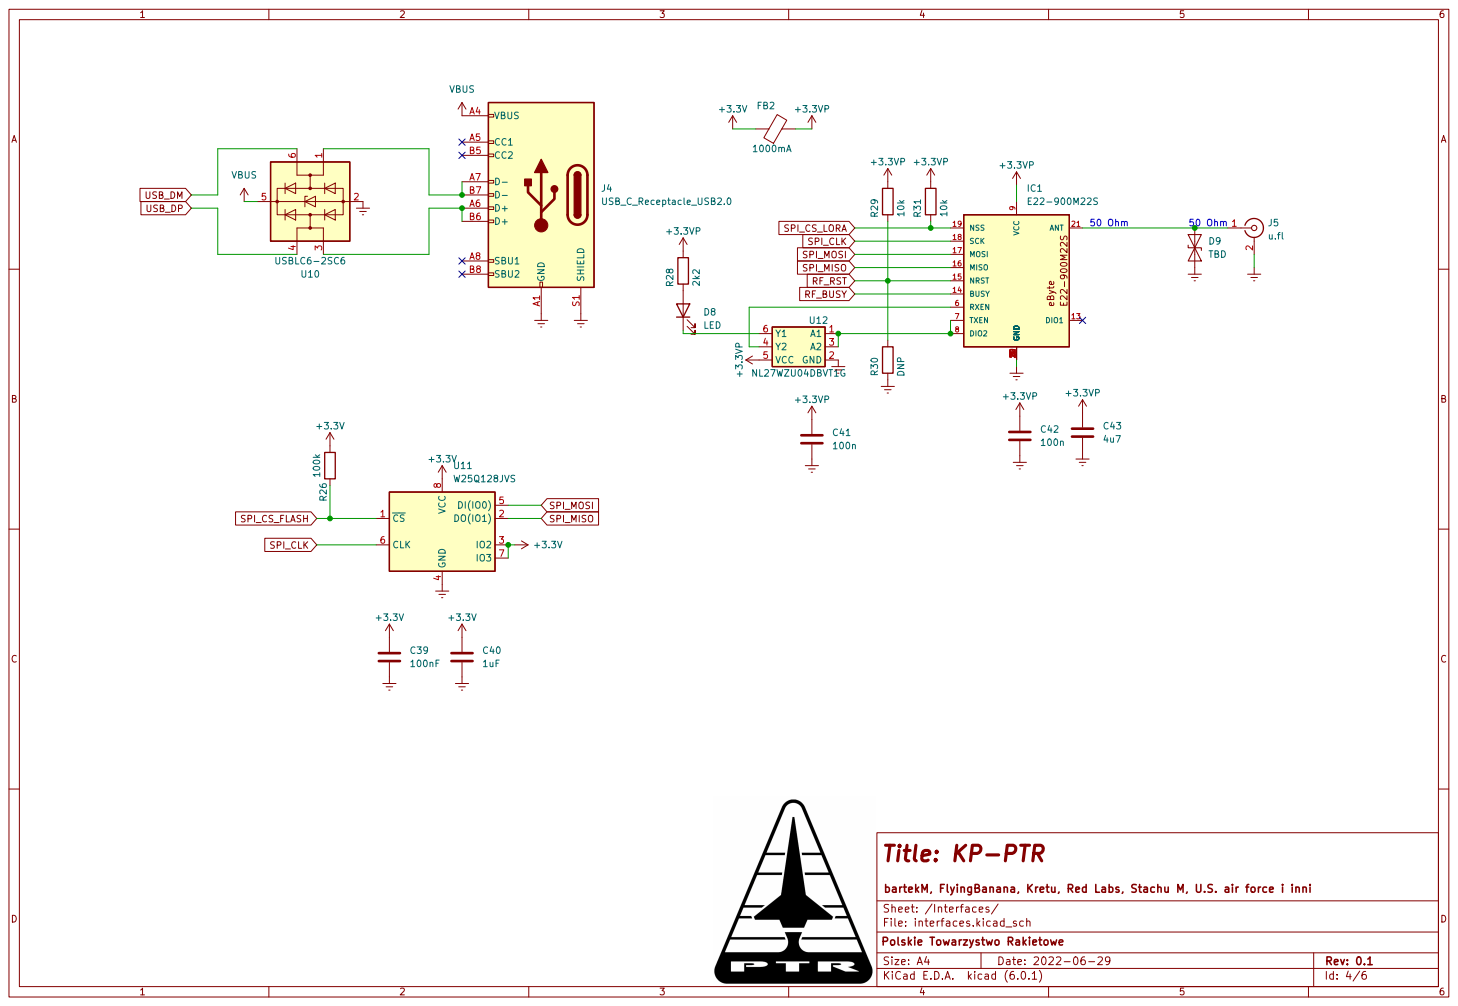
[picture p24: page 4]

11012 DIO1 13 BUSY 14 NRST 15 MISO 16 MOSI 17 SCK 18 NSS 19 GND

220 ANT 21 22345 RXEN 6 TXEN 7 DIO2 8 VCC

Id: 4/6 Title: KP-PTR

bartekM, FlyingBanana, Kretu, Red Labs, Stachu M, U.S. air force i inni
File: interfaces.kicad_sch Sheet: /Interfaces/ Polskie Towarzystwo Rakietowe

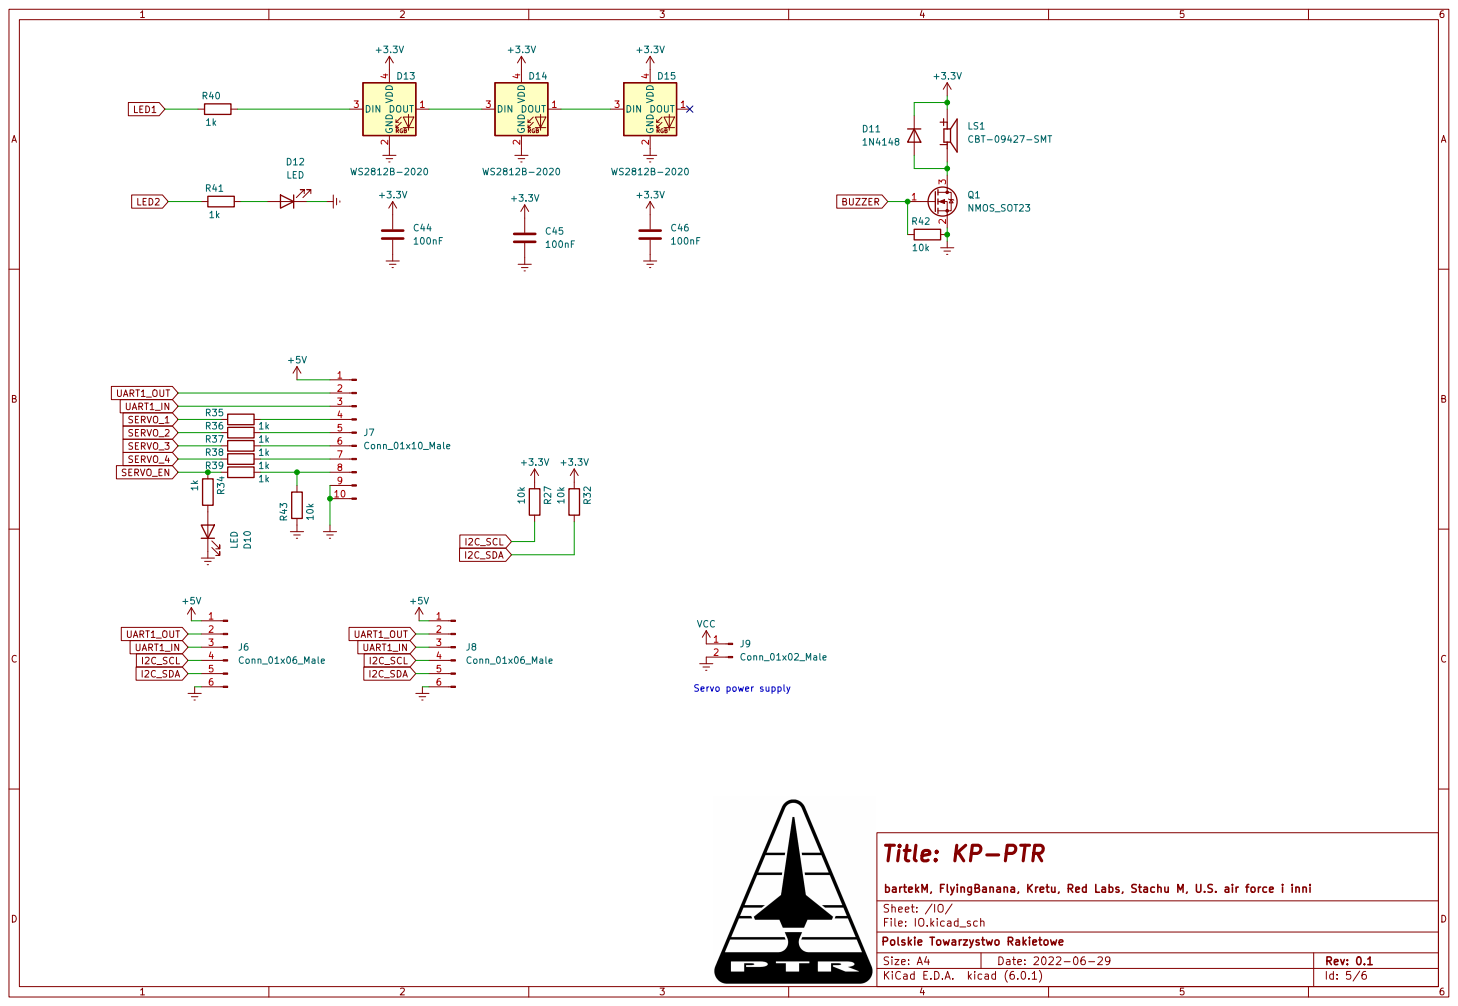
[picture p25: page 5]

Id: 5/6 Title: KP-PTR

bartekM, FlyingBanana, Kretu, Red Labs, Stachu M, U.S. air force i inni
File: IO.kicad_sch Sheet: /IO/ Polskie Towarzystwo Rakietowe

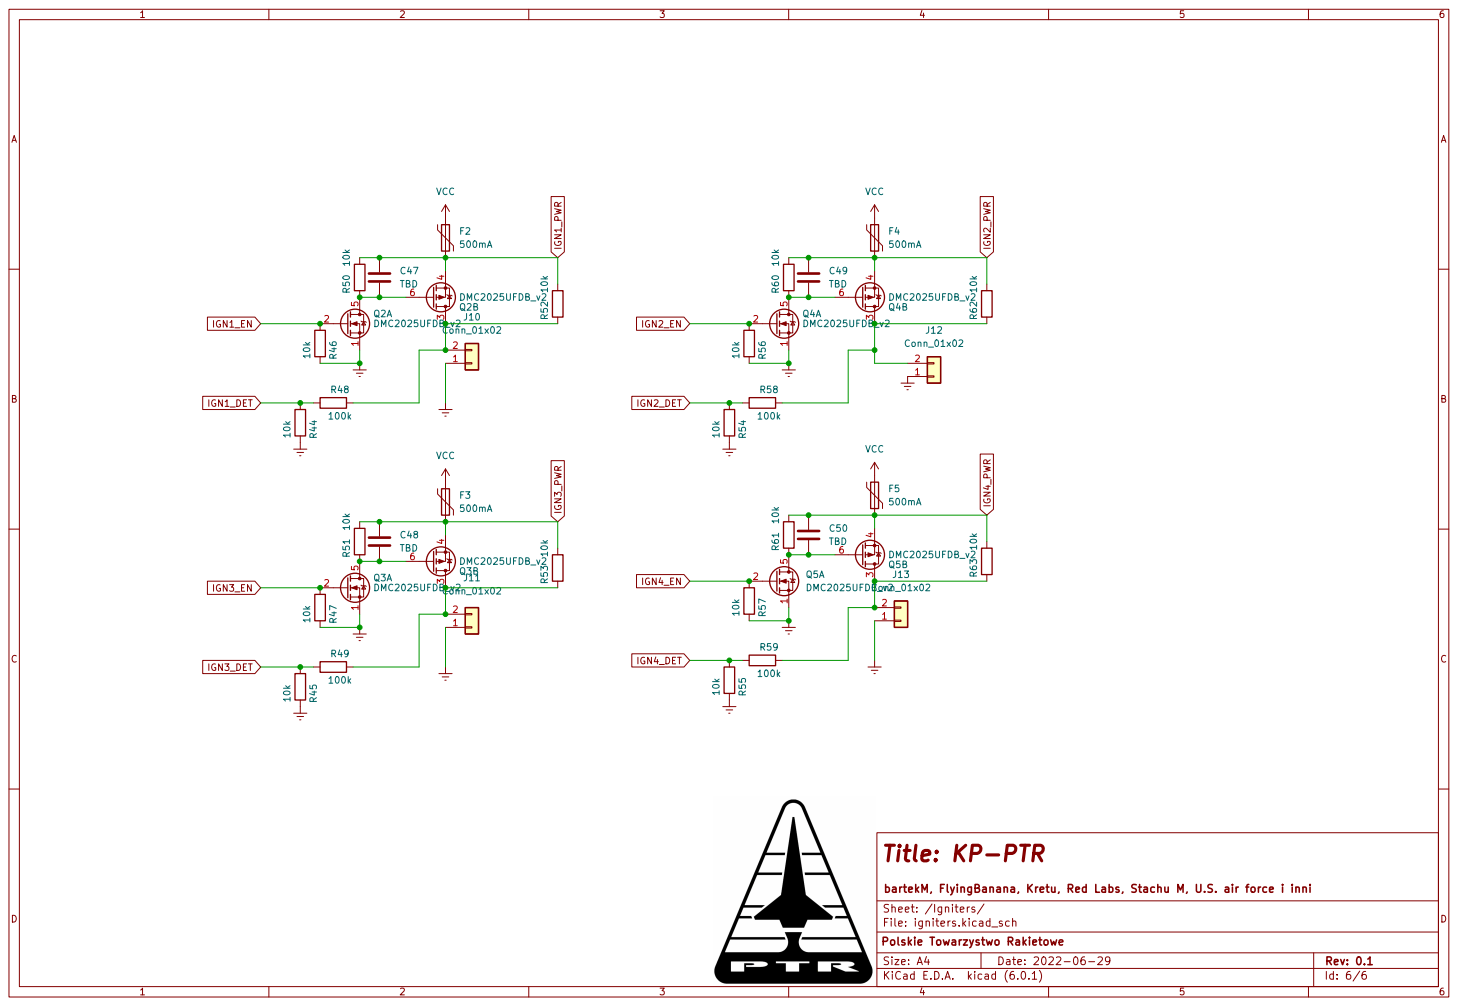
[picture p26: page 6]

bartekM, FlyingBanana, Kretu, Red Labs, Stachu M, U.S. air force i inni 3 4

Id: 6/6 Title: KP-PTR

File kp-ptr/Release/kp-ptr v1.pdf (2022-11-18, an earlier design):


https://www.espressif.com/sites/default/files/documentation/esp32-s3_hardware_design_guidelines_en.pdf
https://dl.espressif.com/dl/SCH_ESP32-S3-DEVKITC-1_V1_20210312C.pdf
https://www.espressif.com/sites/default/files/documentation/esp32-s3-wroom-1_wroom-1u_datasheet_en.pdf

Power supply File: PSU.kicad_sch

Interfaces File: interfaces.kicad_sch Sensors File: sensors.kicad_sch

Strapping pin | USB-JTAG = pullup

Id: 1/6 Title: KP-PTR

bartekM, FlyingBanana, Kretu, Red Labs, Stachu M, U.S. air force i inni
File: kp-ptr.kicad_sch Sheet: / Polskie Towarzystwo Rakietowe


bartekM, FlyingBanana, Kretu, Red Labs, Stachu M, U.S. air force i inni +3.3V

Id: 2/6 Title: KP-PTR

File: sensors.kicad_sch Sheet: /Sensors/ Polskie Towarzystwo Rakietowe


bartekM, FlyingBanana, Kretu, Red Labs, Stachu M, U.S. air force i inni C41

Id: 3/6 Title: KP-PTR


11012 DIO1 13 BUSY 14 NRST 15 MISO 16 MOSI 17 SCK 18 NSS 19 GND

220 ANT 21 22345 RXEN 6 TXEN 7 DIO2 8 VCC

Id: 4/6 Title: KP-PTR

bartekM, FlyingBanana, Kretu, Red Labs, Stachu M, U.S. air force i inni
File: interfaces.kicad_sch Sheet: /Interfaces/ Polskie Towarzystwo Rakietowe


Id: 5/6 Title: KP-PTR

bartekM, FlyingBanana, Kretu, Red Labs, Stachu M, U.S. air force i inni
File: IO.kicad_sch Sheet: /IO/ Polskie Towarzystwo Rakietowe


bartekM, FlyingBanana, Kretu, Red Labs, Stachu M, U.S. air force i inni 1
J12 Conn_01x02

Id: 6/6 Title: KP-PTR

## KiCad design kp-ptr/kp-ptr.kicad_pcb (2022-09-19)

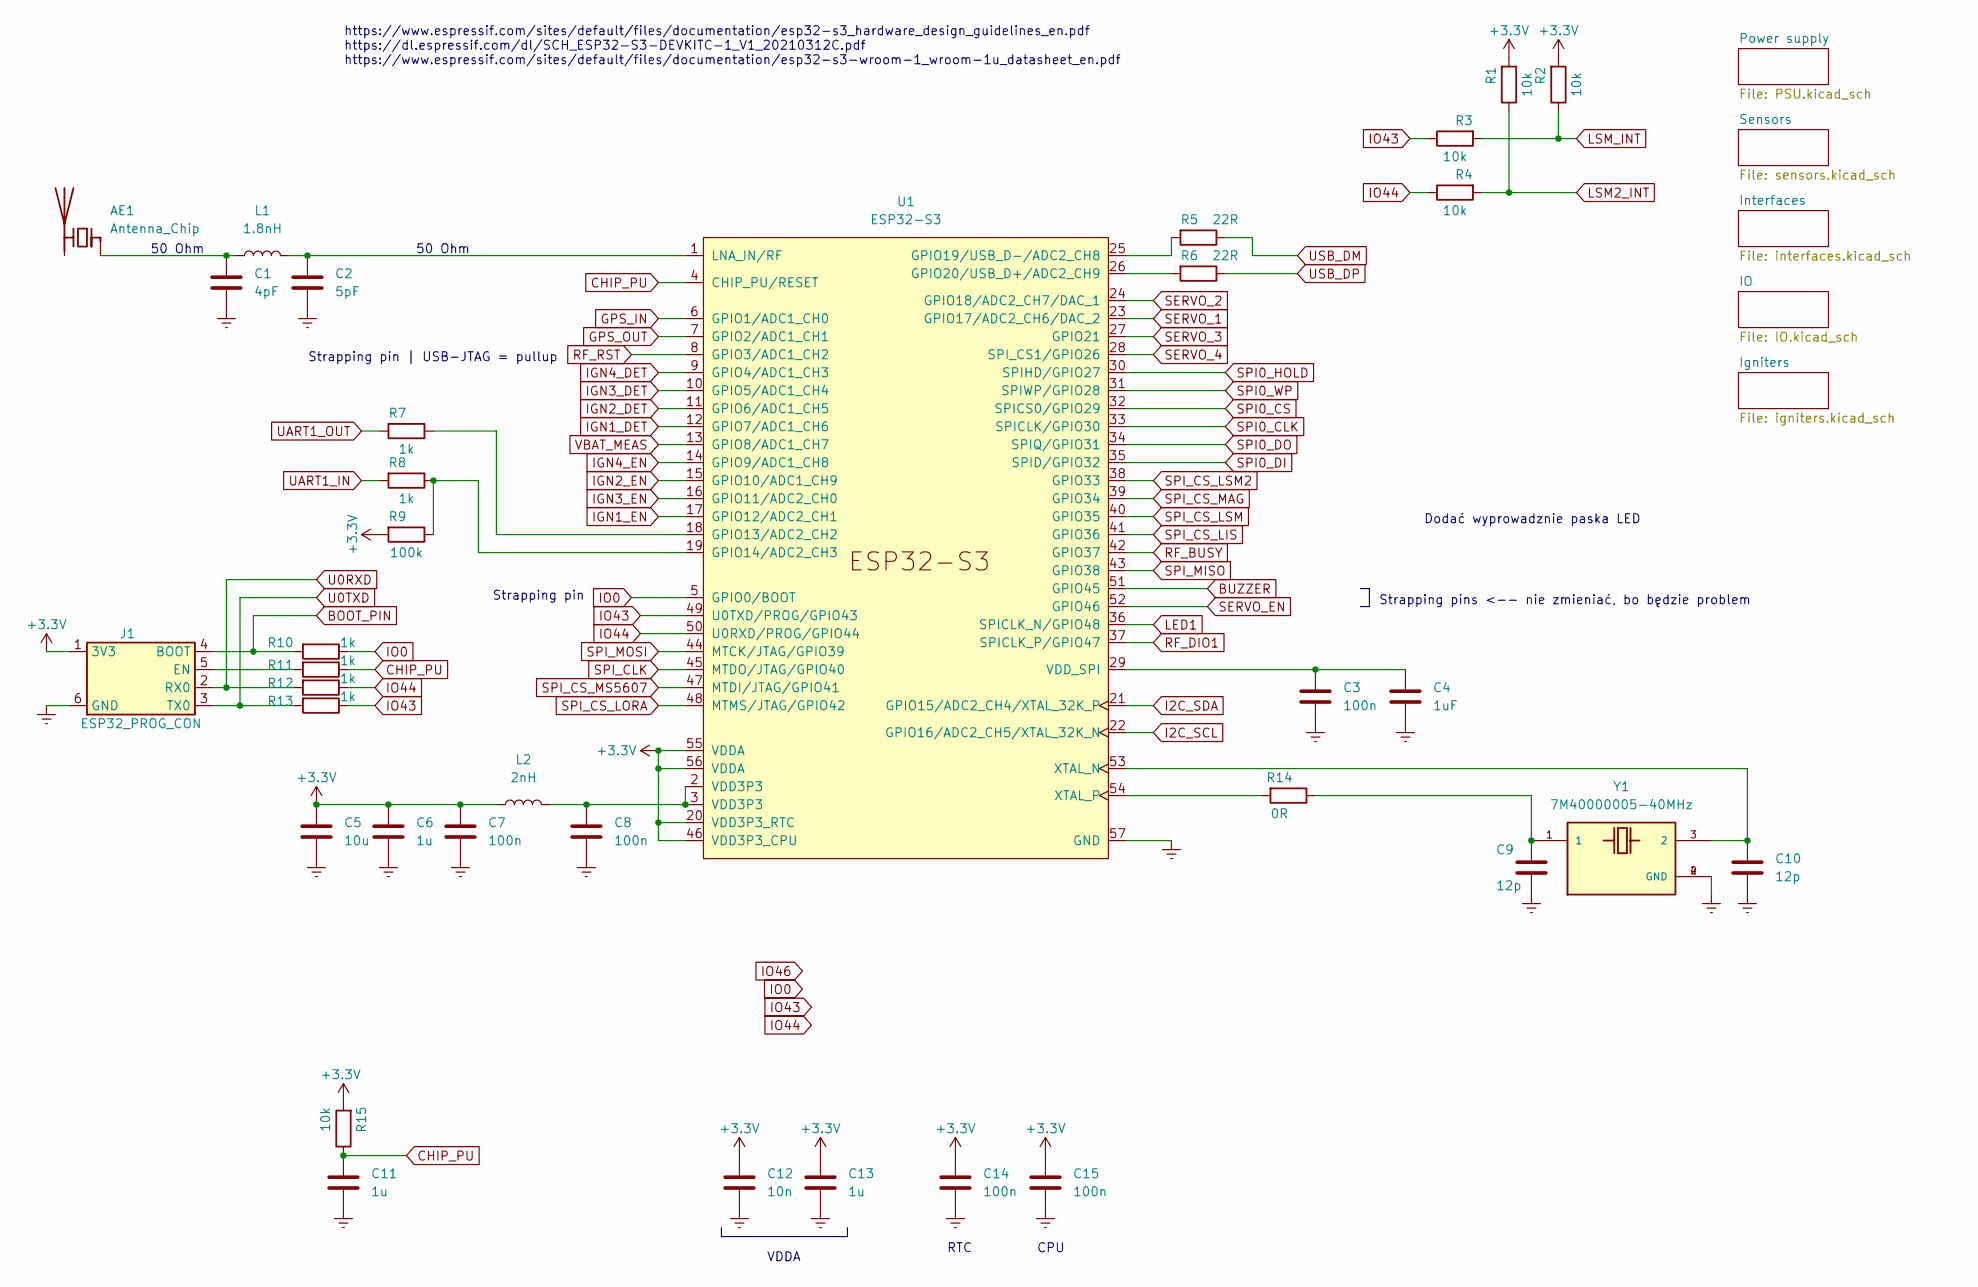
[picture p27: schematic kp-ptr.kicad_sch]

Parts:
AE1: Antenna_Chip; AMCA31-2R450G-S1F-T3
C1: 4pF; C_0402_1005Metric
C2: 5pF; C_0402_1005Metric
C3, C7, C8, C14, C15: 100n; C_0402_1005Metric
C4: 1uF; C_0402_1005Metric
C5: 10u; C_0603_1608Metric
C6, C11, C13: 1u; C_0402_1005Metric
C9, C10: 12p; C_0402_1005Metric
C12: 10n; C_0402_1005Metric
J1: ESP32_PROG_CON; PinHeader_1x06_P1.27mm_Vertical
L1: 1.8nH; L_0402_1005Metric
L2: 2nH; L_0402_1005Metric
R1, R2, R3, R4, R15: 10k; R_0402_1005Metric
R5, R6: 22R; R_0402_1005Metric
R7, R8, R10, R11, R12, R13: 1k; R_0402_1005Metric
R9: 100k; R_0402_1005Metric
R14: 0R; R_0402_1005Metric
U1: ESP32-S3
Y1: 7M40000005-40MHz; XTAL_TSX-3225_16.0000MF18X-AC3

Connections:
+3V3: C5.1, C6.1, C7.1, C12.1, C13.1, C14.1, C15.1, J1.1 (3V3), L2.1, R1.2, R2.2, R9.2, R15.2, U1.20 (VDD3P3_RTC), U1.46 (VDD3P3_CPU), U1.55 (VDDA), U1.56 (VDDA); also elsewhere on the board
BOOT_PIN: J1.4 (BOOT), R10.2
BUZZER: U1.51 (GPIO45); also elsewhere on the board
CHIP_PU: C11.2, R11.1, R15.1, U1.4 (CHIP_PU/RESET)
Earth: C1.2, C2.2, C3.2, C4.2, C5.2, C6.2, C7.2, C8.2, C9.1, C10.2, C11.1, C12.2, C13.2, C14.2, C15.2, J1.6 (GND), U1.57 (GND), Y1.2 (GND), Y1.4 (GND); also elsewhere on the board
GPS_IN: U1.6 (GPIO1/ADC1_CH0); also elsewhere on the board
GPS_OUT: U1.7 (GPIO2/ADC1_CH1); also elsewhere on the board
I2C_SCL: U1.22 (GPIO16/ADC2_CH5/XTAL_32K_N); also elsewhere on the board
I2C_SDA: U1.21 (GPIO15/ADC2_CH4/XTAL_32K_P); also elsewhere on the board
IGN1_DET: U1.12 (GPIO7/ADC1_CH6); also elsewhere on the board
IGN1_EN: U1.17 (GPIO12/ADC2_CH1); also elsewhere on the board
IGN2_DET: U1.11 (GPIO6/ADC1_CH5); also elsewhere on the board
IGN2_EN: U1.15 (GPIO10/ADC1_CH9); also elsewhere on the board
IGN3_DET: U1.10 (GPIO5/ADC1_CH4); also elsewhere on the board
IGN3_EN: U1.16 (GPIO11/ADC2_CH0); also elsewhere on the board
IGN4_DET: U1.9 (GPIO4/ADC1_CH3); also elsewhere on the board
IGN4_EN: U1.14 (GPIO9/ADC1_CH8); also elsewhere on the board
IO0: R10.1, U1.5 (GPIO0/BOOT)
IO43: R3.1, R13.1, U1.49 (U0TXD/PROG/GPIO43)
IO44: R4.1, R12.1, U1.50 (U0RXD/PROG/GPIO44)
LED1: U1.36 (SPICLK_N/GPIO48); also elsewhere on the board
LSM2_INT: R1.1, R4.2; also elsewhere on the board
LSM_INT: R2.1, R3.2; also elsewhere on the board
unnamed: AE1.1 (FEED), C1.1, L1.1
unnamed: C2.1, L1.2, U1.1 (LNA_IN/RF)
unnamed: C3.1, C4.1, U1.29 (VDD_SPI)
unnamed: C8.1, L2.2, U1.2 (VDD3P3), U1.3 (VDD3P3)
unnamed: C9.2, R14.1, Y1.1
unnamed: C10.1, U1.53 (XTAL_N), Y1.3 (2)
unnamed: J1.5 (EN), R11.2
unnamed: R5.2, U1.25 (GPIO19/USB_D-/ADC2_CH8)
unnamed: R6.2, U1.26 (GPIO20/USB_D+/ADC2_CH9)
unnamed: R7.1, U1.18 (GPIO13/ADC2_CH2)
unnamed: R8.1, R9.1, U1.19 (GPIO14/ADC2_CH3)
unnamed: R14.2, U1.54 (XTAL_P)
RF_BUSY: U1.42 (GPIO37); also elsewhere on the board
RF_DIO1: U1.37 (SPICLK_P/GPIO47); also elsewhere on the board
RF_RST: U1.8 (GPIO3/ADC1_CH2); also elsewhere on the board
SERVO_1: U1.23 (GPIO17/ADC2_CH6/DAC_2); also elsewhere on the board
SERVO_2: U1.24 (GPIO18/ADC2_CH7/DAC_1); also elsewhere on the board
SERVO_3: U1.27 (GPIO21); also elsewhere on the board
SERVO_4: U1.28 (SPI_CS1/GPIO26); also elsewhere on the board
SERVO_EN: U1.52 (GPIO46); also elsewhere on the board
SPI0_CLK: U1.33 (SPICLK/GPIO30); also elsewhere on the board
SPI0_CS: U1.32 (SPICS0/GPIO29); also elsewhere on the board
SPI0_DI: U1.35 (SPID/GPIO32); also elsewhere on the board
SPI0_DO: U1.34 (SPIQ/GPIO31); also elsewhere on the board
SPI0_HOLD: U1.30 (SPIHD/GPIO27); also elsewhere on the board
SPI0_WP: U1.31 (SPIWP/GPIO28); also elsewhere on the board
SPI_CLK: U1.45 (MTDO/JTAG/GPIO40); also elsewhere on the board
SPI_CS_LIS: U1.41 (GPIO36); also elsewhere on the board
SPI_CS_LORA: U1.48 (MTMS/JTAG/GPIO42); also elsewhere on the board
SPI_CS_LSM: U1.40 (GPIO35); also elsewhere on the board
SPI_CS_LSM2: U1.38 (GPIO33); also elsewhere on the board
SPI_CS_MAG: U1.39 (GPIO34); also elsewhere on the board
SPI_CS_MS5607: U1.47 (MTDI/JTAG/GPIO41); also elsewhere on the board
SPI_MISO: U1.43 (GPIO38); also elsewhere on the board
SPI_MOSI: U1.44 (MTCK/JTAG/GPIO39); also elsewhere on the board
U0RXD: J1.2 (RX0), R12.2
U0TXD: J1.3 (TX0), R13.2
UART1_IN: R8.2; also elsewhere on the board
UART1_OUT: R7.2; also elsewhere on the board
USB_DM: R5.1; also elsewhere on the board
USB_DP: R6.1; also elsewhere on the board
VBAT_MEAS: U1.13 (GPIO8/ADC1_CH7); also elsewhere on the board

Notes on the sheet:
https://www.espressif.com/sites/default/files/documentation/esp32-s3_hardware_design_guidelines_en.pdf https://dl.espressif.com/dl/SCH_ESP32-S3-DEVKITC-1_V1_20210312C.pdf https://www.espressif.com/sites/default/files/documentation/esp32-s3-wroom-1_wroom-1u_datasheet_en.pdf
50 Ohm
Strapping pin
VDDA
CPU
Strapping pins <-- nie zmieniać, bo będzie problem
Dodać wyprowadznie paska LED
Strapping pin | USB-JTAG = pullup
RTC

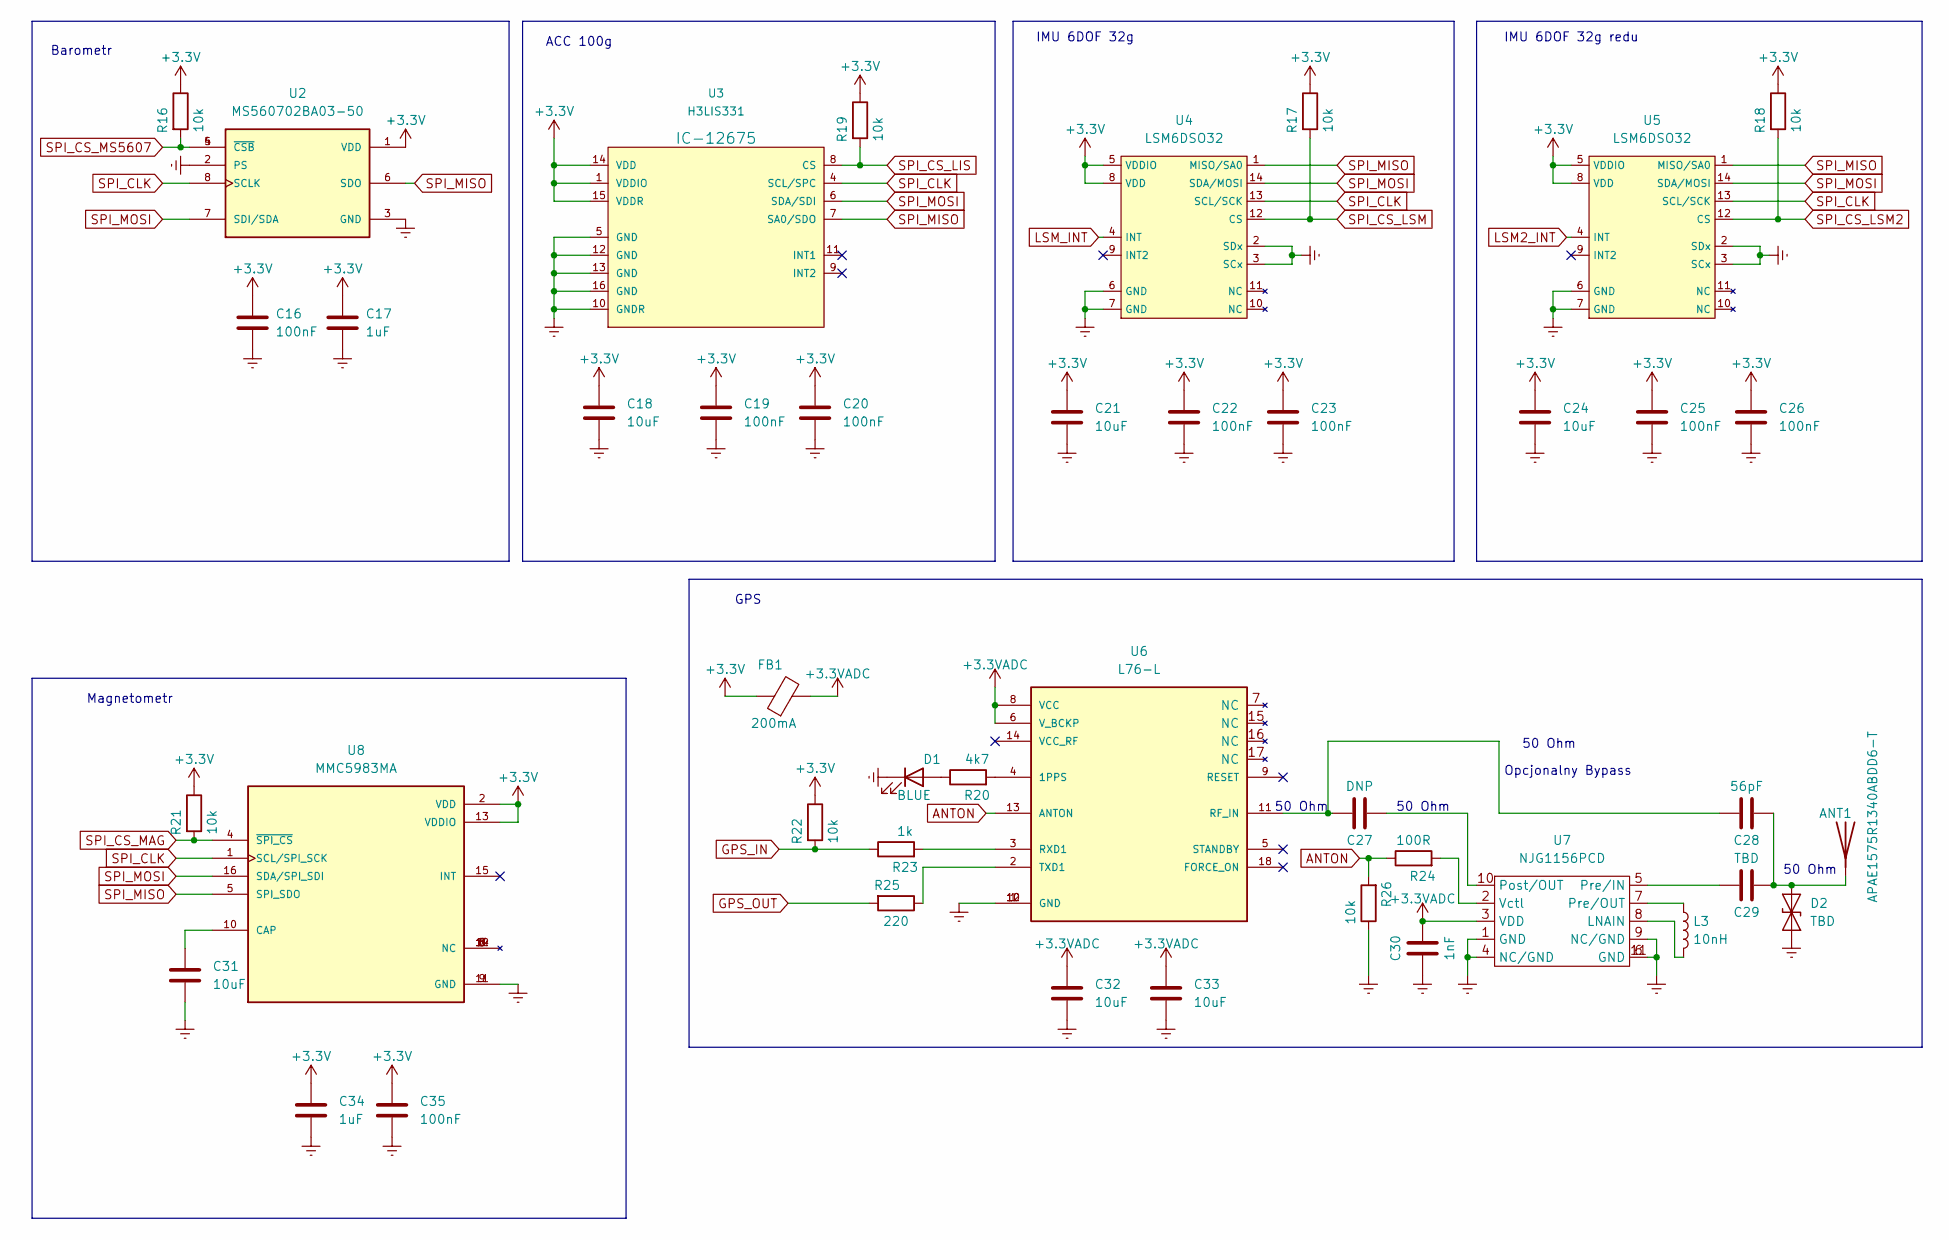
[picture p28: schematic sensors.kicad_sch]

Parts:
ANT1: APAE1575R1340ABDD6-T; APAE1575 13x13x4mm GPS Patch Antenna
C16, C19, C20, C22, C23, C25, C26, C35: 100nF; C_0402_1005Metric
C17, C34: 1uF; C_0402_1005Metric
C18, C21, C24, C31, C32, C33: 10uF; C_0603_1608Metric
C27: DNP; C_0402_1005Metric
C28: 56pF; C_0402_1005Metric
C29: TBD; C_0402_1005Metric
C30: 1nF; C_0402_1005Metric
D1: BLUE; LED_0603_1608Metric
D2: TBD; D_0402_1005Metric
FB1: 200mA; R_0402_1005Metric
L3: 10nH; L_0402_1005Metric
R16, R17, R18, R19, R21, R22, R26: 10k; R_0402_1005Metric
R20: 4k7; R_0402_1005Metric
R23: 1k; R_0402_1005Metric
R24: 100R; R_0402_1005Metric
R25: 220; R_0402_1005Metric
U2: MS560702BA03-50; MS5607
U3: H3LIS331; LIS331
U4, U5: LSM6DSO32
U6: L76-L; XCVR_L76-L; PARTREV 3.1
U7: NJG1156PCD; SON50P260X260X55-11N
U8: MMC5983MA; PARTREV A

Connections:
+3.3VADC: C30.2, C32.1, C33.1, FB1.2, U6.6 (V_BCKP), U6.8 (VCC), U7.3 (VDD)
+3V3: C16.1, C17.1, C18.1, C19.1, C20.1, C21.1, C22.1, C23.1, C24.1, C25.1, C26.1, C34.1, C35.1, FB1.1, R16.1, R17.1, R18.1, R19.1, R21.1, R22.1, U2.1 (VDD), U3.1 (VDDIO), U3.14 (VDD), U3.15 (VDDR), U4.5 (VDDIO), U4.8 (VDD), U5.5 (VDDIO), U5.8 (VDD), U8.2 (VDD), U8.13 (VDDIO); also elsewhere on the board
ANTON: R24.1, R26.2, U6.13 (ANTON)
Earth: C16.2, C17.2, C18.2, C19.2, C20.2, C21.2, C22.2, C23.2, C24.2, C25.2, C26.2, C30.1, C31.2, C32.2, C33.2, C34.2, C35.2, D1.1 (K), D2.1 (A1), R26.1, U2.2 (PS), U2.3 (GND), U3.5 (GND), U3.10 (GNDR), U3.12 (GND), U3.13 (GND), U3.16 (GND), U4.2 (SDx), U4.3 (SCx), U4.6 (GND), U4.7 (GND), U5.2 (SDx), U5.3 (SCx), U5.6 (GND), U5.7 (GND), U6.1 (GND), U6.10 (GND), U6.12 (GND), U7.1 (GND), U7.4 (NC/GND), U7.6 (GND), U7.9 (NC/GND), U7.11 (GND), U8.9 (GND), U8.11 (GND); also elsewhere on the board
GPS_IN: R22.2, R23.1; also elsewhere on the board
GPS_OUT: R25.2; also elsewhere on the board
LSM2_INT: U5.4 (INT); also elsewhere on the board
LSM_INT: U4.4 (INT); also elsewhere on the board
unnamed: ANT1.1 (A), C28.1, C29.1, D2.2 (A2)
unnamed: C27.1, U7.10 (Post/OUT)
unnamed: C27.2, C28.2, U6.11 (RF_IN)
unnamed: C29.2, U7.5 (Pre/IN)
unnamed: C31.1, U8.10 (CAP)
unnamed: D1.2 (A), R20.1
unnamed: L3.1, U7.7 (Pre/OUT)
unnamed: L3.2, U7.8 (LNAIN)
unnamed: R20.2, U6.4 (1PPS)
unnamed: R23.2, U6.3 (RXD1)
unnamed: R24.2, U7.2 (Vctl)
unnamed: R25.1, U6.2 (TXD1)
SPI_CLK: U2.8 (SCLK), U3.4 (SCL/SPC), U4.13 (SCL/SCK), U5.13 (SCL/SCK), U8.1 (SCL/SPI_SCK); also elsewhere on the board
SPI_CS_LIS: R19.2, U3.8 (CS); also elsewhere on the board
SPI_CS_LSM: R17.2, U4.12 (CS); also elsewhere on the board
SPI_CS_LSM2: R18.2, U5.12 (CS); also elsewhere on the board
SPI_CS_MAG: R21.2, U8.4 (~SPI_CS); also elsewhere on the board
SPI_CS_MS5607: R16.2, U2.4 (~CSB), U2.5 (~CSB); also elsewhere on the board
SPI_MISO: U2.6 (SDO), U3.7 (SA0/SDO), U4.1 (MISO/SA0), U5.1 (MISO/SA0), U8.5 (SPI_SDO); also elsewhere on the board
SPI_MOSI: U2.7 (SDI/SDA), U3.6 (SDA/SDI), U4.14 (SDA/MOSI), U5.14 (SDA/MOSI), U8.16 (SDA/SPI_SDI); also elsewhere on the board

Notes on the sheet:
Barometr
50 Ohm
Magnetometr
IMU 6DOF 32g
Opcjonalny Bypass
GPS
IMU 6DOF 32g redu
ACC 100g

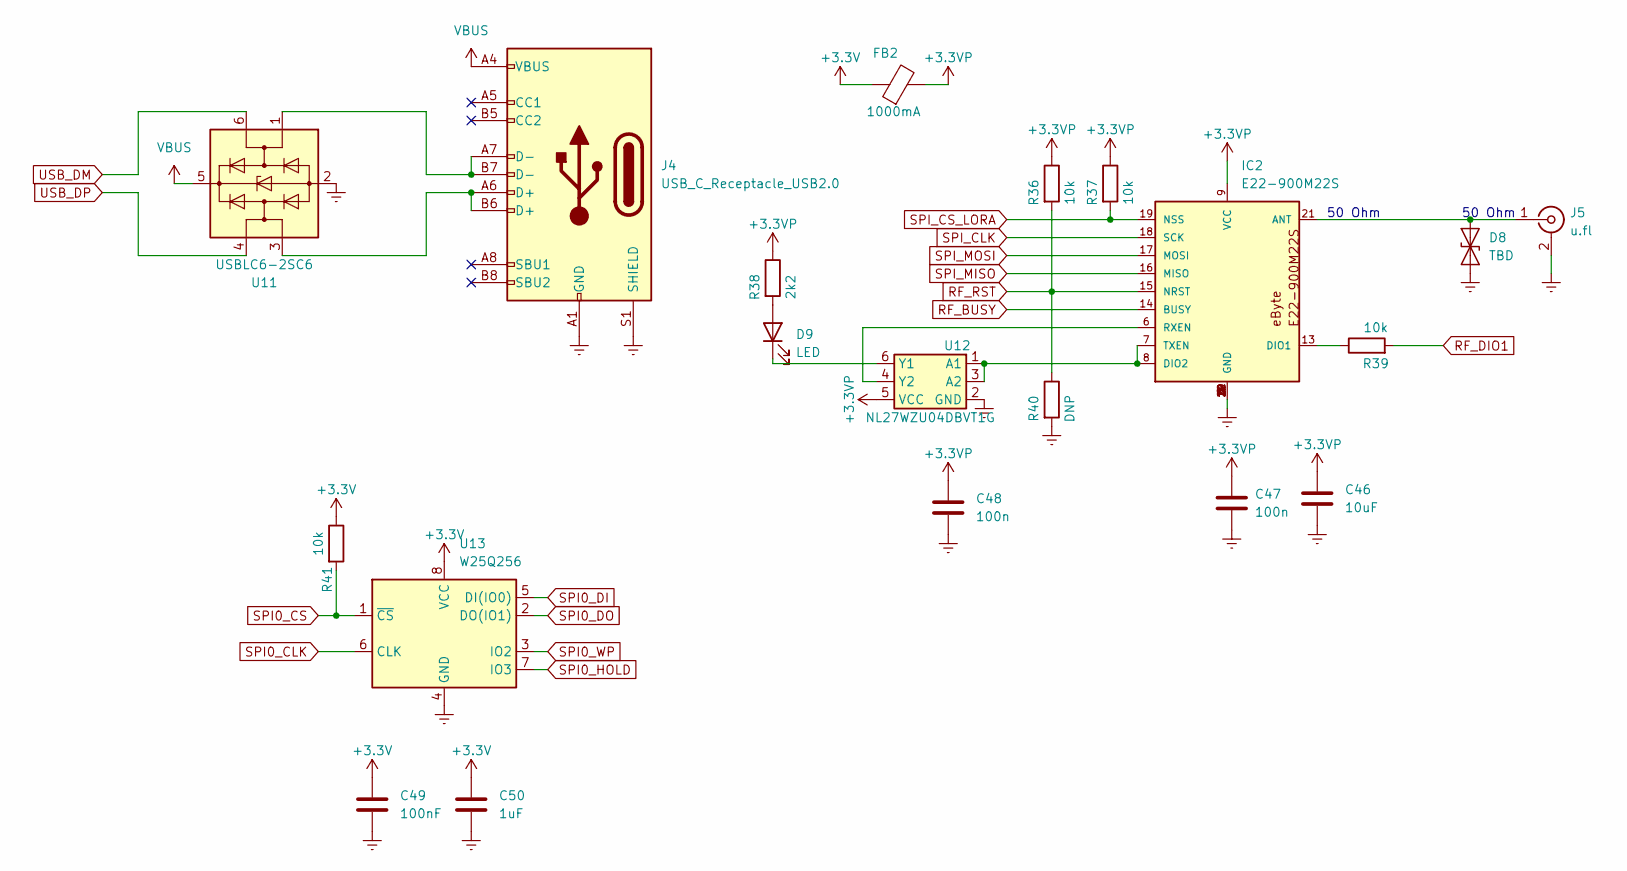
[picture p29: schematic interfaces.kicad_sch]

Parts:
C46: 10uF; C_0603_1608Metric
C47, C48: 100n; C_0402_1005Metric
C49: 100nF; C_0402_1005Metric
C50: 1uF; C_0402_1005Metric
D8: TBD; D_0402_1005Metric
D9: LED; LED_0603_1608Metric
FB2: 1000mA; R_0603_1608Metric
IC2: E22-900M22S
J4: USB_C_Receptacle_USB2.0; USB_C_213716
J5: u.fl; SMA_Amphenol_132289_EdgeMount
R36, R37, R39, R41: 10k; R_0402_1005Metric
R38: 2k2; R_0402_1005Metric
R40: DNP; R_0402_1005Metric
U11: USBLC6-2SC6; SOT-23-6
U12: NL27WZU04DBVT1G; SOT95P275X110-6N
U13: W25Q256; SON127P800X600X80-9N-D

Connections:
+3.3VP: C46.1, C47.1, C48.1, FB2.2, IC2.9 (VCC), R36.1, R37.1, R38.1, U12.5 (VCC)
+3V3: C49.1, C50.1, FB2.1, R41.1, U13.8 (VCC); also elsewhere on the board
Earth: C46.2, C47.2, C48.2, C49.2, C50.2, D8.1 (A1), IC2.1 (GND), IC2.2 (GND), IC2.3 (GND), IC2.4 (GND), IC2.5 (GND), IC2.10 (GND), IC2.11 (GND), IC2.12 (GND), IC2.20 (GND), IC2.22 (GND), J4.A1 (GND), J4.A12 (GND), J4.B1 (GND), J4.B12 (GND), J4.S1 (SHIELD), J5.2 (Ext), R40.2, U11.2 (GND), U12.2 (GND), U13.4 (GND), U13.9; also elsewhere on the board
unnamed: D8.2 (A2), IC2.21 (ANT), J5.1 (In)
unnamed: D9.1 (K), U12.6 (Y1)
unnamed: D9.2 (A), R38.2
unnamed: IC2.6 (RXEN), U12.4 (Y2)
unnamed: IC2.7 (TXEN), IC2.8 (DIO2), U12.1 (A1), U12.3 (A2)
unnamed: IC2.13 (DIO1), R39.1
unnamed: J4.A6 (D+), J4.B6 (D+), U11.3 (I/O2)
unnamed: J4.A7 (D-), J4.B7 (D-), U11.1 (I/O1)
RF_BUSY: IC2.14 (BUSY); also elsewhere on the board
RF_DIO1: R39.2; also elsewhere on the board
RF_RST: IC2.15 (NRST), R36.2, R40.1; also elsewhere on the board
SPI0_CLK: U13.6 (CLK); also elsewhere on the board
SPI0_CS: R41.2, U13.1 (~CS); also elsewhere on the board
SPI0_DI: U13.5 (DI(IO0)); also elsewhere on the board
SPI0_DO: U13.2 (DO(IO1)); also elsewhere on the board
SPI0_HOLD: U13.7 (IO3); also elsewhere on the board
SPI0_WP: U13.3 (IO2); also elsewhere on the board
SPI_CLK: IC2.18 (SCK); also elsewhere on the board
SPI_CS_LORA: IC2.19 (NSS), R37.2; also elsewhere on the board
SPI_MISO: IC2.16 (MISO); also elsewhere on the board
SPI_MOSI: IC2.17 (MOSI); also elsewhere on the board
USB_DM: U11.6 (I/O1); also elsewhere on the board
USB_DP: U11.4 (I/O2); also elsewhere on the board
VBUS: J4.A4 (VBUS), J4.A9 (VBUS), J4.B4 (VBUS), J4.B9 (VBUS), U11.5 (VBUS); also elsewhere on the board

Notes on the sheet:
50 Ohm

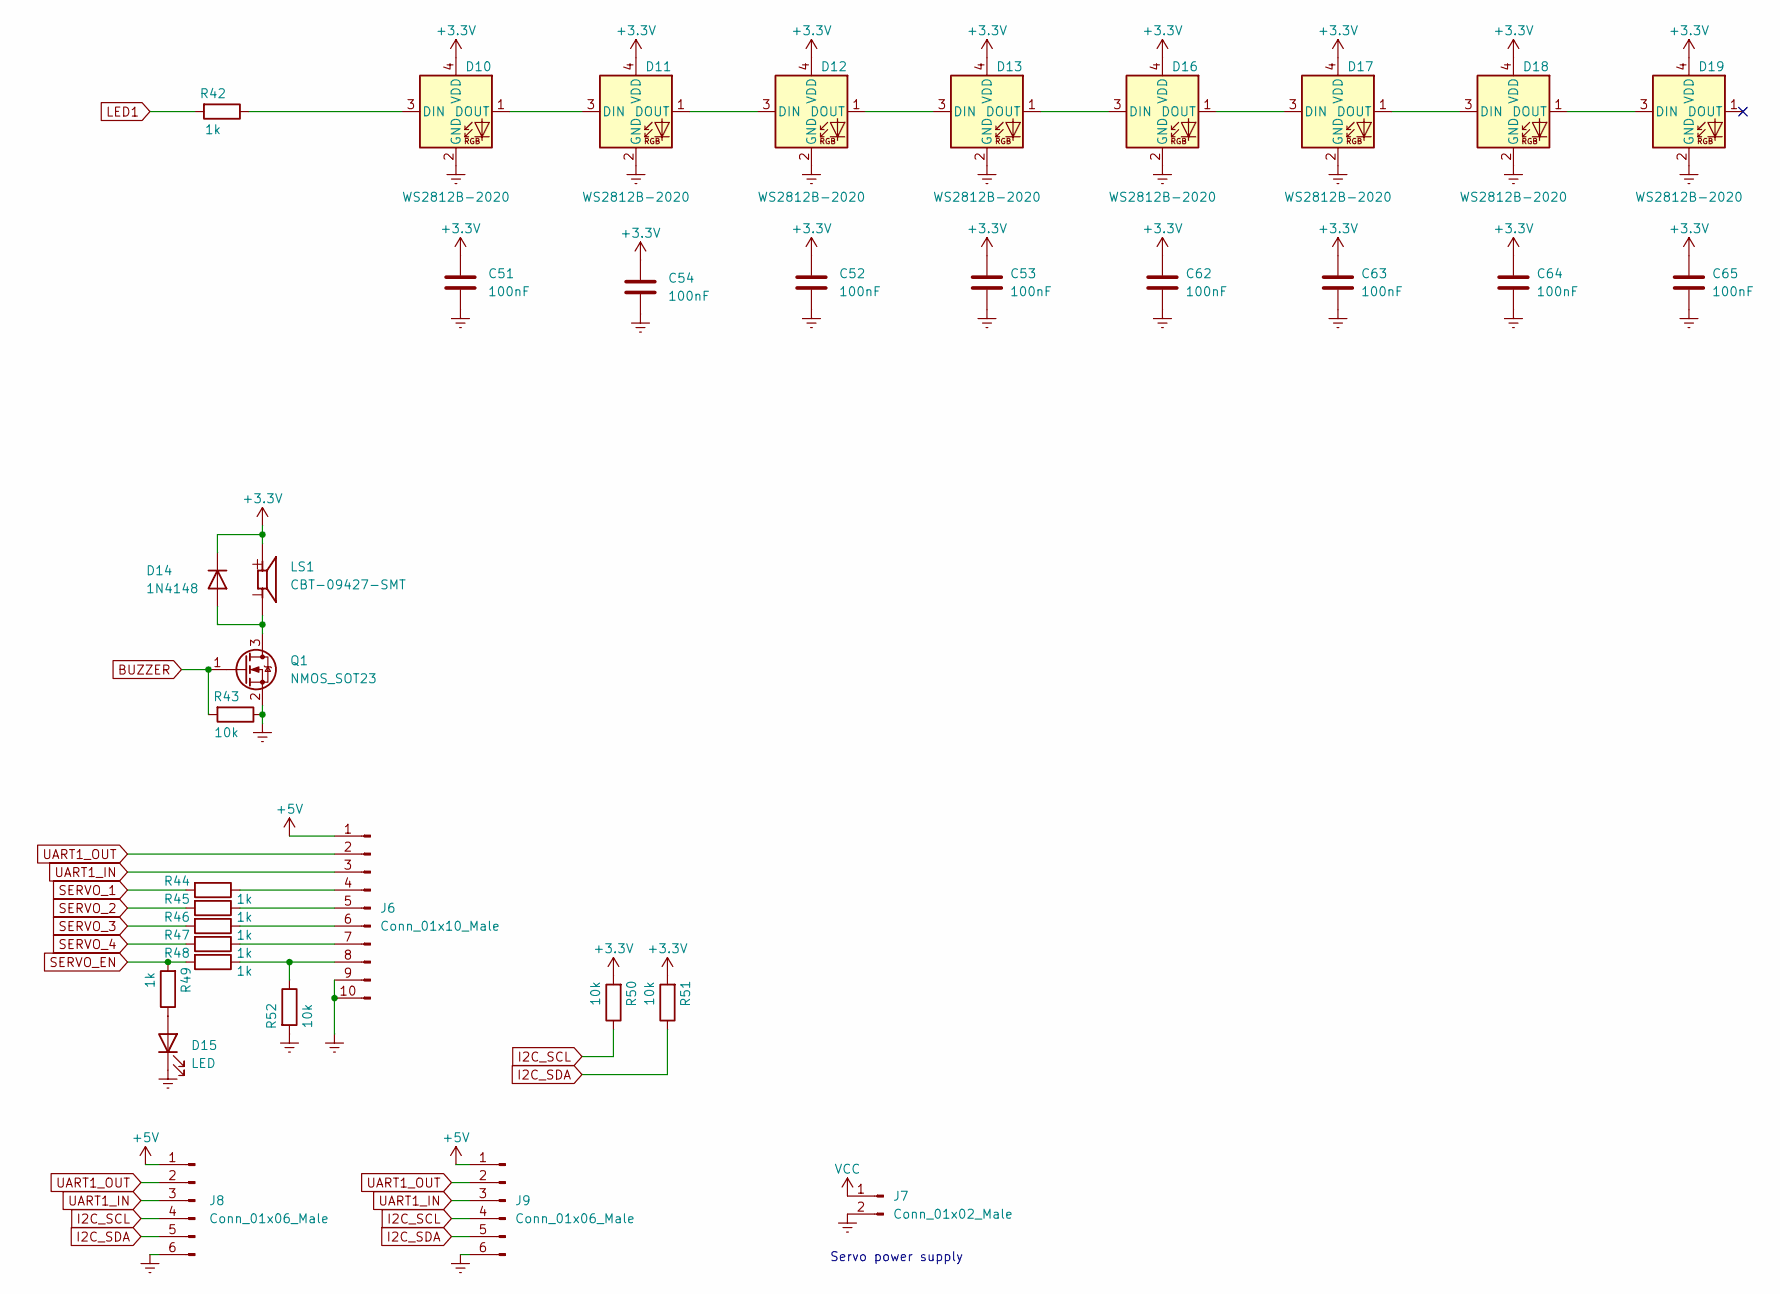
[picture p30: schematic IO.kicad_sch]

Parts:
C51, C52, C53, C54, C62, C63, C64, C65: 100nF; C_0402_1005Metric
D10, D11, D12, D13, D16, D17, D18, D19: WS2812B-2020
D14: 1N4148; D_SOD-123
D15: LED; LED_0603_1608Metric
J6: Conn_01x10_Male; JST_GH_BM10B-GHS-TBT_1x10-1MP_P1.25mm_Vertical
J7: Conn_01x02_Male; TerminalBlock_TE_282834-2_1x02_P2.54mm_Horizontal
J8, J9: Conn_01x06_Male; JST_GH_BM06B-GHS-TBT_1x06-1MP_P1.25mm_Vertical
LS1: CBT-09427-SMT; Buzzer_12x9.5RM7.6
Q1: NMOS_SOT23; SOT-23
R42, R44, R45, R46, R47, R48, R49: 1k; R_0402_1005Metric
R43, R50, R51, R52: 10k; R_0402_1005Metric

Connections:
+3V3: C51.1, C52.1, C53.1, C54.1, C62.1, C63.1, C64.1, C65.1, D10.4 (VDD), D11.4 (VDD), D12.4 (VDD), D13.4 (VDD), D14.1 (K), D16.4 (VDD), D17.4 (VDD), D18.4 (VDD), D19.4 (VDD), LS1.1 (+), R50.2, R51.2; also elsewhere on the board
+5V: J6.1, J8.1, J9.1; also elsewhere on the board
BUZZER: Q1.1 (G), R43.2; also elsewhere on the board
Earth: C51.2, C52.2, C53.2, C54.2, C62.2, C63.2, C64.2, C65.2, D10.2 (GND), D11.2 (GND), D12.2 (GND), D13.2 (GND), D15.1 (K), D16.2 (GND), D17.2 (GND), D18.2 (GND), D19.2 (GND), J6.9, J6.10, J6.MP, J7.2, J8.6, J8.MP, J9.6, J9.MP, Q1.2 (S), R43.1, R52.2; also elsewhere on the board
I2C_SCL: J8.4, J9.4, R50.1; also elsewhere on the board
I2C_SDA: J8.5, J9.5, R51.1; also elsewhere on the board
LED1: R42.2; also elsewhere on the board
unnamed: D10.1 (DOUT), D11.3 (DIN)
unnamed: D10.3 (DIN), R42.1
unnamed: D11.1 (DOUT), D12.3 (DIN)
unnamed: D12.1 (DOUT), D13.3 (DIN)
unnamed: D13.1 (DOUT), D16.3 (DIN)
unnamed: D14.2 (A), LS1.2 (-), Q1.3 (D)
unnamed: D15.2 (A), R49.1
unnamed: D16.1 (DOUT), D17.3 (DIN)
unnamed: D17.1 (DOUT), D18.3 (DIN)
unnamed: D18.1 (DOUT), D19.3 (DIN)
unnamed: J6.4, R44.1
unnamed: J6.5, R45.1
unnamed: J6.6, R46.1
unnamed: J6.7, R47.1
unnamed: J6.8, R48.1, R52.1
SERVO_1: R44.2; also elsewhere on the board
SERVO_2: R45.2; also elsewhere on the board
SERVO_3: R46.2; also elsewhere on the board
SERVO_4: R47.2; also elsewhere on the board
SERVO_EN: R48.2, R49.2; also elsewhere on the board
UART1_IN: J6.3, J8.3, J9.3; also elsewhere on the board
UART1_OUT: J6.2, J8.2, J9.2; also elsewhere on the board
VCC: J7.1; also elsewhere on the board

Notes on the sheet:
Servo power supply

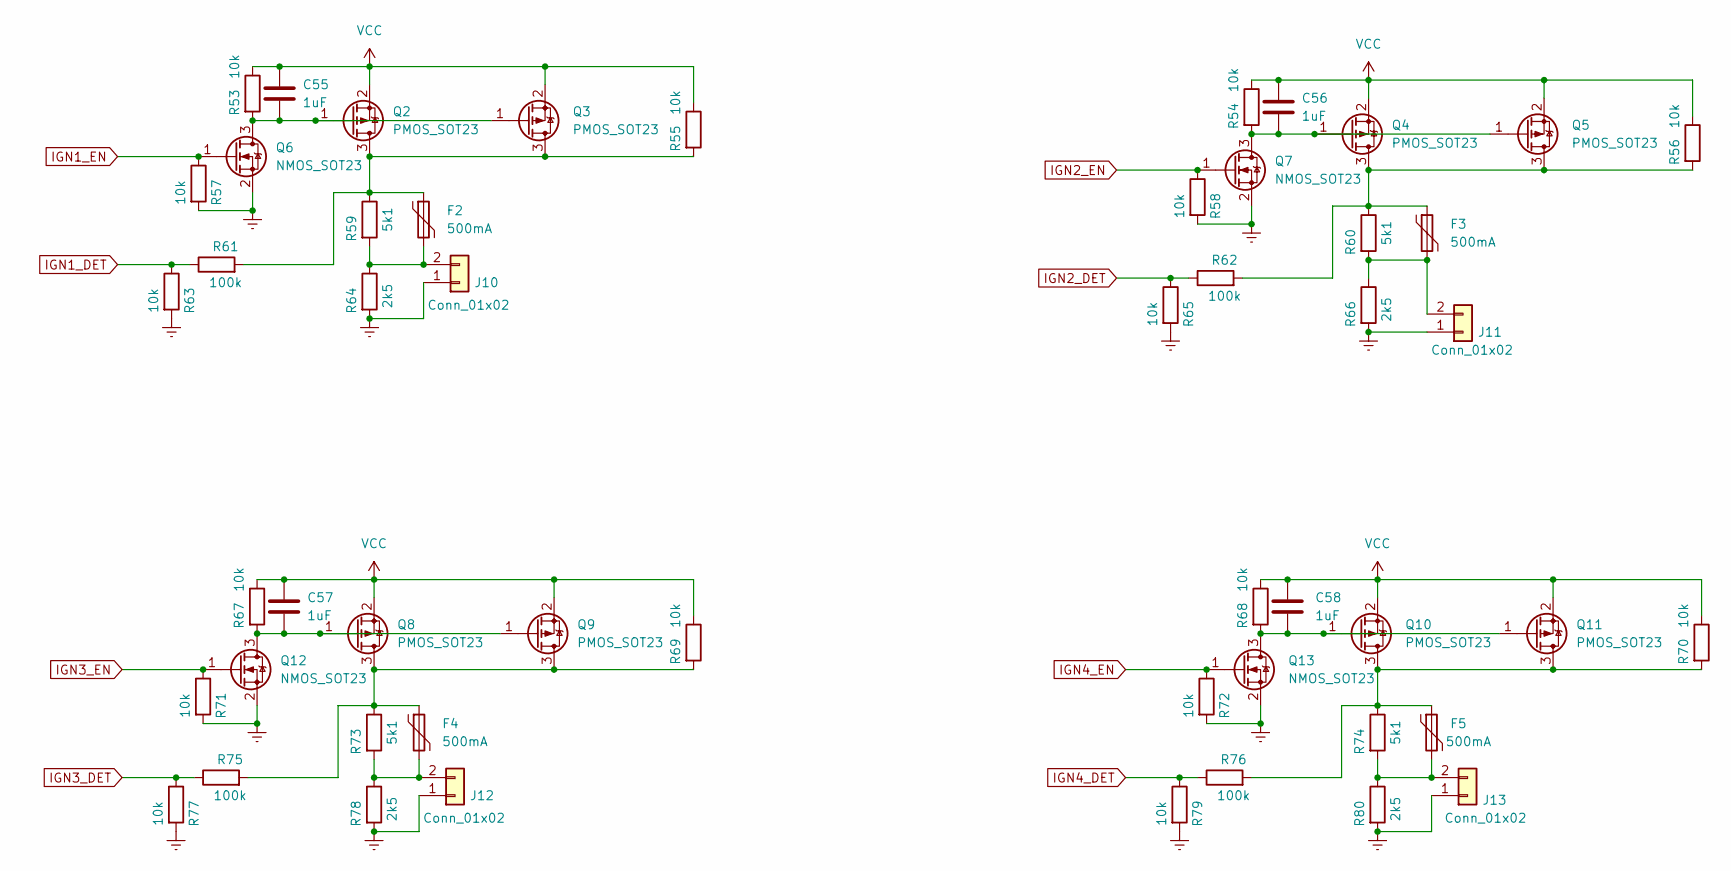
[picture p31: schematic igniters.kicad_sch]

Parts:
C55, C56, C57, C58: 1uF; C_0402_1005Metric
F2, F3, F4, F5: 500mA; Fuse_1206_3216Metric
J10, J11, J12, J13: Conn_01x02; TerminalBlock_TE_282834-2_1x02_P2.54mm_Horizontal
Q2, Q3, Q4, Q5, Q8, Q9, Q10, Q11: PMOS_SOT23; SOT-23
Q6, Q7, Q12, Q13: NMOS_SOT23; SOT-23
R53, R54, R55, R56, R57, R58, R63, R65, R67, R68, R69, R70, R71, R72, R77, R79: 10k; R_0402_1005Metric
R59, R60, R73, R74: 5k1; R_0402_1005Metric
R61, R62, R75, R76: 100k; R_0402_1005Metric
R64, R66, R78, R80: 2k5; R_0402_1005Metric

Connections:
Earth: J10.1, J11.1, J12.1, J13.1, Q6.2 (S), Q7.2 (S), Q12.2 (S), Q13.2 (S), R57.2, R58.2, R63.2, R64.2, R65.2, R66.2, R71.2, R72.2, R77.2, R78.2, R79.2, R80.2; also elsewhere on the board
IGN1_DET: R61.1, R63.1; also elsewhere on the board
IGN1_EN: Q6.1 (G), R57.1; also elsewhere on the board
IGN2_DET: R62.1, R65.1; also elsewhere on the board
IGN2_EN: Q7.1 (G), R58.1; also elsewhere on the board
IGN3_DET: R75.1, R77.1; also elsewhere on the board
IGN3_EN: Q12.1 (G), R71.1; also elsewhere on the board
IGN4_DET: R76.1, R79.1; also elsewhere on the board
IGN4_EN: Q13.1 (G), R72.1; also elsewhere on the board
unnamed: C55.2, Q2.1 (G), Q3.1 (G), Q6.3 (D), R53.2
unnamed: C56.2, Q4.1 (G), Q5.1 (G), Q7.3 (D), R54.2
unnamed: C57.2, Q8.1 (G), Q9.1 (G), Q12.3 (D), R67.2
unnamed: C58.2, Q10.1 (G), Q11.1 (G), Q13.3 (D), R68.2
unnamed: F2.1, Q2.3 (D), Q3.3 (D), R55.2, R59.1, R61.2
unnamed: F2.2, J10.2, R59.2, R64.1
unnamed: F3.1, Q4.3 (D), Q5.3 (D), R56.2, R60.1, R62.2
unnamed: F3.2, J11.2, R60.2, R66.1
unnamed: F4.1, Q8.3 (D), Q9.3 (D), R69.2, R73.1, R75.2
unnamed: F4.2, J12.2, R73.2, R78.1
unnamed: F5.1, Q10.3 (D), Q11.3 (D), R70.2, R74.1, R76.2
unnamed: F5.2, J13.2, R74.2, R80.1
VCC: C55.1, C56.1, C57.1, C58.1, Q2.2 (S), Q3.2 (S), Q4.2 (S), Q5.2 (S), Q8.2 (S), Q9.2 (S), Q10.2 (S), Q11.2 (S), R53.1, R54.1, R55.1, R56.1, R67.1, R68.1, R69.1, R70.1; also elsewhere on the board

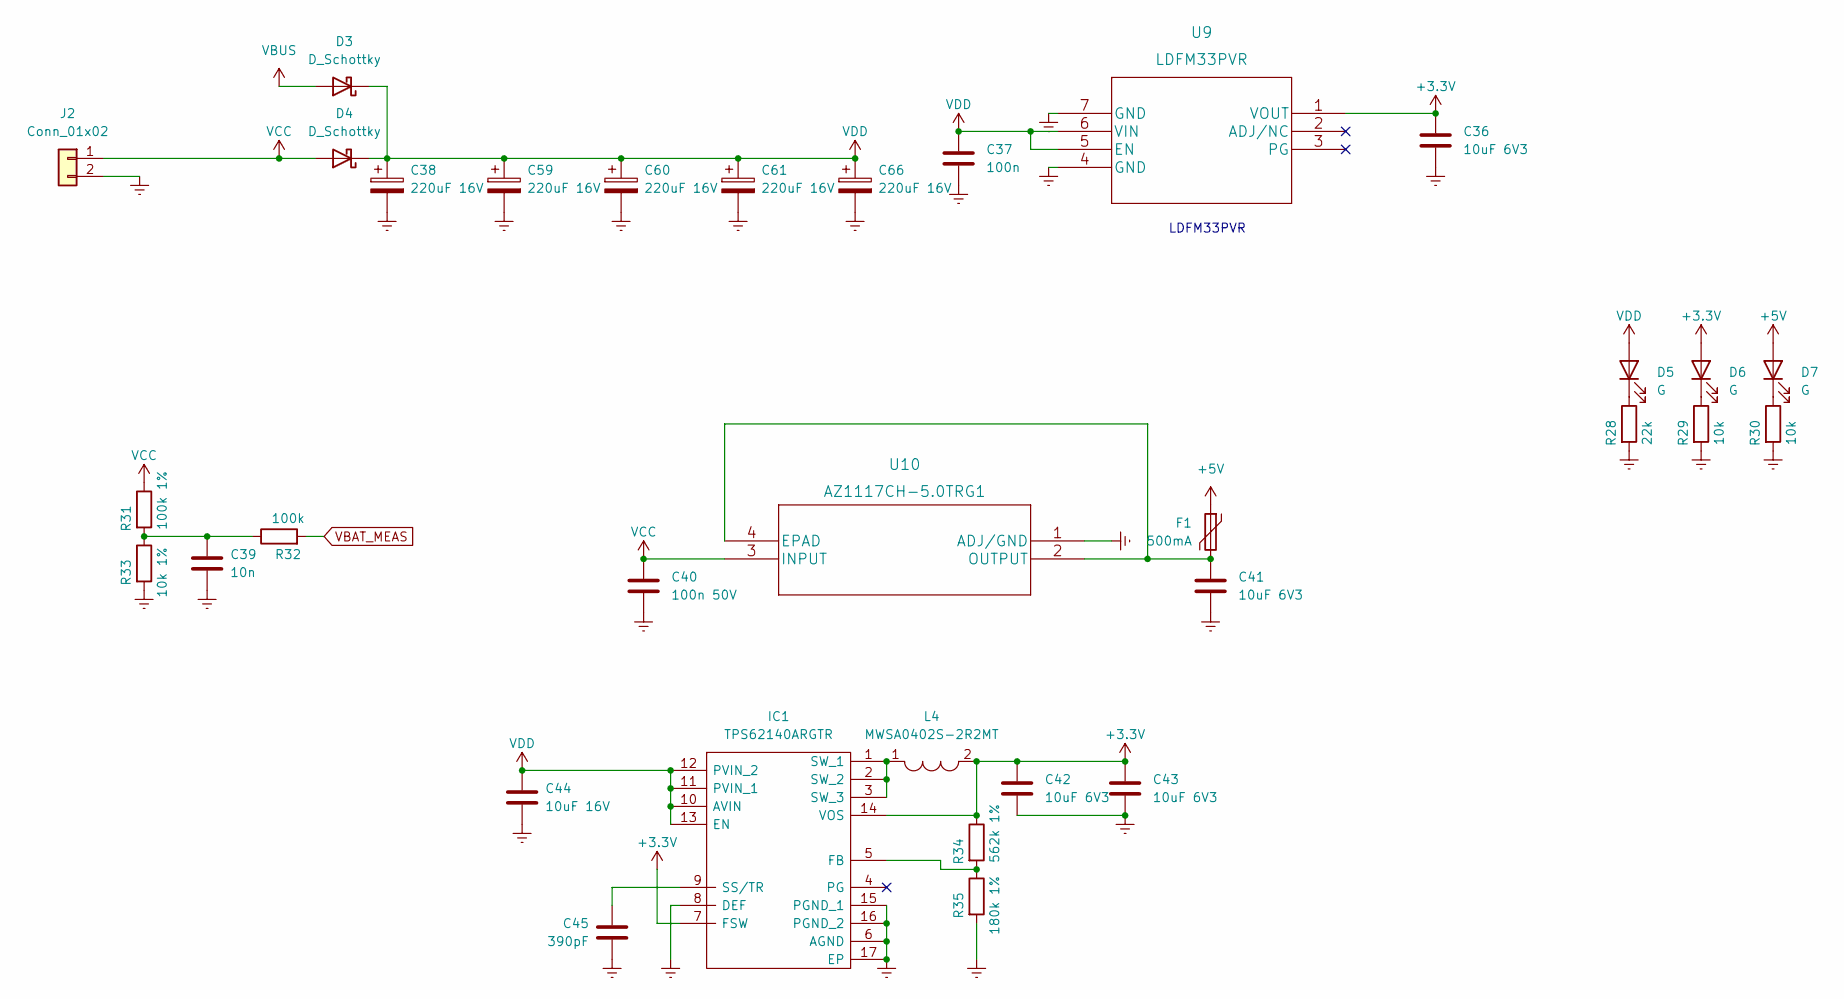
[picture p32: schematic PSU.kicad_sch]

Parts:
C36, C41, C42, C43: 10uF 6V3; C_0603_1608Metric
C37: 100n; C_0402_1005Metric
C38, C59, C60, C61, C66: 220uF 16V; CP_EIA-7343-31_Kemet-D
C39: 10n; C_0402_1005Metric
C40: 100n 50V; C_0402_1005Metric
C44: 10uF 16V; C_0603_1608Metric
C45: 390pF; C_0402_1005Metric
D3, D4: D_Schottky; D_SOD-123
D5, D6, D7: G; LED_0603_1608Metric
F1: 500mA; Fuse_1206_3216Metric
IC1: TPS62140ARGTR; QFN50P300X300X100-17N-D; Manufacturer_Part_Number TPS62140ARGTR; Mouser Part Number 595-TPS62140ARGTR
J2: Conn_01x02; TerminalBlock_TE_282834-2_1x02_P2.54mm_Horizontal
L4: MWSA0402S-2R2MT; INDPM4442X200N
R28: 22k; R_0402_1005Metric
R29, R30: 10k; R_0402_1005Metric
R31: 100k 1%; R_0402_1005Metric
R32: 100k; R_0402_1005Metric
R33: 10k 1%; R_0402_1005Metric
R34: 562k 1%; R_0402_1005Metric
R35: 180k 1%; R_0402_1005Metric
U9: LDFM33PVR
U10: AZ1117CH-5.0TRG1

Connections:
+3V3: C36.1, C42.1, C43.1, D6.2 (A), IC1.7 (FSW), IC1.14 (VOS), L4.2, R34.1, U9.1 (VOUT); also elsewhere on the board
+5V: D7.2 (A), F1.1; also elsewhere on the board
Earth: C36.2, C37.2, C38.2, C39.2, C40.2, C41.2, C42.2, C43.2, C44.2, C45.1, C59.2, C60.2, C61.2, C66.2, IC1.6 (AGND), IC1.8 (DEF), IC1.15 (PGND_1), IC1.16 (PGND_2), IC1.17 (EP), J2.2, R28.2, R29.2, R30.2, R33.2, R35.2, U9.4 (GND), U9.7 (GND), U10.1 (ADJ/GND); also elsewhere on the board
unnamed: C39.1, R31.2, R32.1, R33.1
unnamed: C41.1, F1.2, U10.2 (OUTPUT), U10.4 (EPAD)
unnamed: C45.2, IC1.9 (SS/TR)
unnamed: D5.1 (K), R28.1
unnamed: D6.1 (K), R29.1
unnamed: D7.1 (K), R30.1
unnamed: IC1.1 (SW_1), IC1.2 (SW_2), IC1.3 (SW_3), L4.1
unnamed: IC1.5 (FB), R34.2, R35.1
VBAT_MEAS: R32.2; also elsewhere on the board
VBUS: D3.2 (A); also elsewhere on the board
VCC: C40.1, D4.2 (A), J2.1, R31.1, U10.3 (INPUT); also elsewhere on the board
VDD: C37.1, C38.1, C44.1, C59.1, C60.1, C61.1, C66.1, D3.1 (K), D4.1 (K), D5.2 (A), IC1.10 (AVIN), IC1.11 (PVIN_1), IC1.12 (PVIN_2), IC1.13 (EN), U9.5 (EN), U9.6 (VIN)

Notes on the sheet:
LDFM33PVR

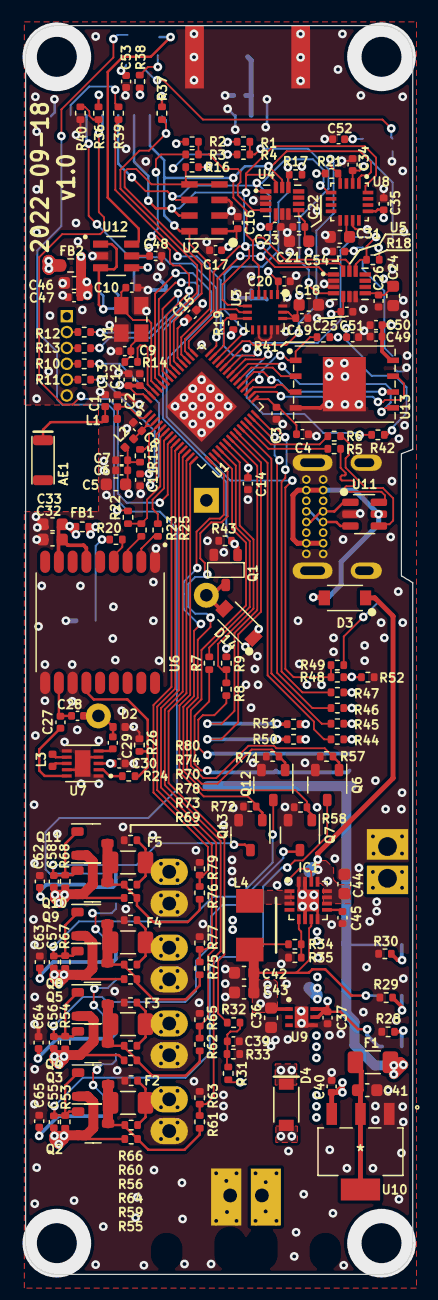
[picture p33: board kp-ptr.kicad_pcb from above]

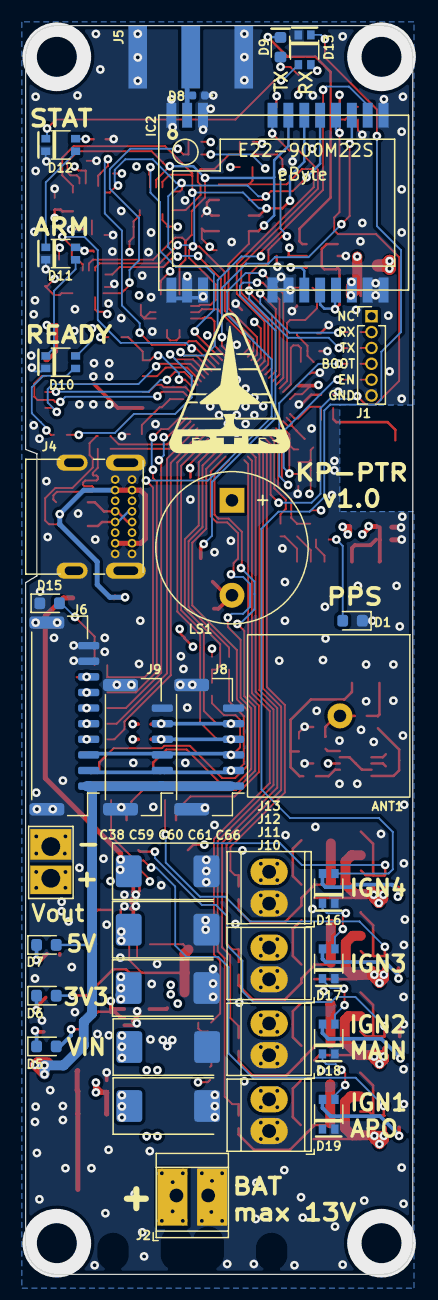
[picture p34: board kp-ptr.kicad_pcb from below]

Board: 4 copper layers, 31.0 x 100.0 mm, 219 parts (35 on the bottom side), 127 nets.

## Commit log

2022-02-07 KiCad libs created
    - ublox GNSS receivers added
    - MS5607 added
    - LIS331 - symbol added
    - ESP32-S3 - symbol added
    - USB C added
    - LSM6DSO32 - symbol added
    [CAM-M8Q-0.step, MS560702BA03-50.step, kp-ptr.kicad_pcb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]
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2022-02-09 Small schematic update
    Added 3.2x2.5mm crystal (symbol + footprint)
    [PSU.kicad_sch, kp-ptr.kicad_sch, sensors.kicad_sch]
2022-02-09 Small schematic update
    [IO.kicad_sch, interfaces.kicad_sch, kp-ptr.kicad_sch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]
2022-02-20 LIS + SDCARD Signed-off-by: kretu <krecik@gmail.com>
    [interfaces.kicad_sch, kp-ptr.kicad_sch, sensors.kicad_sch]
2022-02-20 poprawiony babol przy sd Signed-off-by: kretu <krecik@gmail.com>
    [interfaces.kicad_sch, kp-ptr.kicad_sch]
2022-02-20 SD bez pullupa na CLK jak w gotowym układzie od ST
    [interfaces.kicad_sch, kp-ptr.kicad_sch]
2022-02-20 Dodane IMU
    [kp-ptr.kicad_sch, sensors.kicad_sch]
2022-02-20 Kondensatory przy IMU zgodnie z DS których nie było u Adafruit
    [kp-ptr.kicad_sch, sensors.kicad_sch]
2022-02-22 IGN & PSU added
    [IO.kicad_sch, PSU.kicad_sch, igniters.kicad_sch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]
2022-02-28 LSM6DSO32 added
    [kp-ptr.kicad_sch, sensors.kicad_sch]
2022-03-04 Magnetometr Buzzer 3xLED Signed-off-by: kretu <krecik@gmail.com>
    [IO.kicad_sch, kp-ptr.kicad_sch, sensors.kicad_sch]
2022-03-05 GPS lora wrzucone symbole Signed-off-by: kretu <krecik@gmail.com>
    [interfaces.kicad_sch, kp-ptr.kicad_sch, sensors.kicad_sch]
2022-03-07 GPS Signed-off-by: kretu <krecik@gmail.com>
    [kp-ptr.kicad_sch, sensors.kicad_sch]
2022-03-08 Footprints IN IMU9DOF OUT Signed-off-by: kretu <krecik@gmail.com>
    [IO.kicad_sch, PSU.kicad_sch, igniters.kicad_sch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]
2022-03-09 First sight of pcb Signed-off-by: kretu <krecik@gmail.com>
    [kp-ptr.kicad_pcb, kp-ptr.kicad_sch, sensors.kicad_sch]
2022-03-09 Small changes before sleep Signed-off-by: kretu <krecik@gmail.com>
    [interfaces.kicad_sch, kp-ptr.kicad_pcb, kp-ptr.kicad_sch]
2022-03-11 Golaiath fight with board Signed-off-by: kretu <krecik@gmail.com>
    [PSU.kicad_sch, interfaces.kicad_sch, kp-ptr.kicad_pcb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]
2022-03-14 RF added, multiple small changes
    [IO.kicad_sch, interfaces.kicad_sch, kp-ptr.kicad_sch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]
2022-04-27 Weryfikacja footprintow faza I Signed-off-by: kretu <krecik@gmail.com>
    [IO.kicad_sch, SOT95P275X110-6N.step, interfaces.kicad_sch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]
2022-04-27 Footprinty drobnicy
    [IO.kicad_sch, PSU.kicad_sch, igniters.kicad_sch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]
2022-05-07 Removed SD card
    Added Flash
    [interfaces.kicad_sch, kp-ptr.kicad_sch]
2022-05-07 Ogarnięty GPS i RF do anteny
    [kp-ptr.kicad_sch, sensors.kicad_sch]
2022-05-07 Kilka zmian.
    -dodany tranzystor P/N mosfet do biblioteki i zapalników
    -dodany komentarz o impedancji ścieżek RF
    [APAE1575.STEP, PSU.kicad_sch, igniters.kicad_sch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]
2022-05-09 Szlifowanie schematu
    [IO.kicad_sch, PSU.kicad_sch, interfaces.kicad_sch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]
2022-06-01 Update po spotkaniu
    [IO.kicad_sch, PSU.kicad_sch, igniters.kicad_sch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]
2022-06-02 Footprint mosfeta
    [igniters.kicad_sch, kp-ptr.kicad_pcb, kp-ptr.kicad_sch]
2022-06-03 1 proba zmieszczenia wszystkiego
    [kp-ptr.kicad_pcb]
2022-06-03 1 próba pomieszczenia wszystkiego
    [IO.kicad_sch, PSU.kicad_sch, igniters.kicad_sch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]
2022-06-03 Add some missing 3D models
    [E22-900M22S v2.step, kp-ptr.kicad_pcb, ublox_max_m8.step]
2022-06-04 swiatelko w tunelu aby zmiescic wszystko
    [IO.kicad_sch, PSU.kicad_sch, igniters.kicad_sch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]
2022-06-11 chyba wszystkie footprinty
    [DFN_M33PVR_STM.step, IO.kicad_sch, PSU.kicad_sch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]
2022-06-11 PCB update
    [2137160001.stp, IO.kicad_sch, PSU.kicad_sch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]
2022-06-12 PCB update 2
    [kp-ptr.kicad_pcb]
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2022-06-25 Next PCB update
    -fixes
    -logos added
    [kp-ptr.kicad_pcb]
2022-06-25 Modele 3d uzupelnione i minimalnie poprawione opisy
    [150040GS73240.stp, 282834-2--3DModel-STEP-1.STEP, AZ1117CH-5.0TRG1.stp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]
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2022-06-26 Footprints and PCB update
    [kp-ptr.kicad_pcb, kp-ptr.kicad_sch]
2022-06-26 PCB finished
    Gerbers prepared
    [B_Cu.gbl, B_Paste.gbp, B_Silkscreen.gbo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]
2022-06-27 PCB update
    Teardrops added
    [B_Cu.gbl, B_Paste.gbp, B_Silkscreen.gbo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]
2022-08-06 Update from v0.1 to v1.0
    [PSU.kicad_sch, igniters.kicad_sch, interfaces.kicad_sch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]
2022-08-06 PCB update to v1.0
    [kp-ptr.kicad_pcb]
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2022-09-07 Second LSM added
    Both LSM has INT connected
    Small pins changes
    [IO.kicad_sch, interfaces.kicad_sch, kp-ptr.kicad_pcb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]
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2022-09-08 Igniters rework
    [IO.kicad_sch, igniters.kicad_sch, kp-ptr.kicad_pcb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]
2022-09-09 Igniters rework v2
    [IO.kicad_sch, PSU.kicad_sch, igniters.kicad_sch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]
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2022-09-12 Flash footprint updated
    Overlay cleaning
    [kp-ptr.kicad_pcb]
2022-09-14 DC-DC added
    multiple PCB changes
    [PSU.kicad_sch, kp-ptr.kicad_pcb, kp-ptr.kicad_sch]
2022-09-15 One step closer to perfection!
    [PSU.kicad_sch, kp-ptr.kicad_pcb, kp-ptr.kicad_sch]
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2022-09-19 Backup capacitor changed from electro to tantal.
    Multiple kung fu changes
    [IO.kicad_sch, PSU.kicad_sch, kp-ptr.kicad_pcb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]
2022-09-19 SW removed, tantal added, powerplane rework
    [PSU.kicad_sch, kp-ptr.kicad_pcb, kp-ptr.kicad_sch]
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2023-12-17 New schematic revision v1.1:
    - added 'DNP' info for few components
    - some stylistic improvements
    - added comment about I2C pins glitch
    [IO.kicad_sch, PSU.kicad_sch, igniters.kicad_sch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]
2025-06-22 + Kicad update to 9.0
    + CC resistors added
    [IO.kicad_sch, PSU.kicad_sch, igniters.kicad_sch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]
2025-06-25 - Removed old teardrops polygons
    - Removed unused LDO
    - Removed unused LNA
    + DC-DC with additional capacitors
    + IGN connectors moved closer together
    - removed additional unused resistors for igniter detection
    + small rearrangement of DC-DC etc
    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
    [IO.kicad_sch, PSU.kicad_sch, igniters.kicad_sch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]
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
